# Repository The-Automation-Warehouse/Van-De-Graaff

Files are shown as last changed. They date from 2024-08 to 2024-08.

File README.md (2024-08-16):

# Van-De-Graaff Generator

Made as part of Arcade Hack Club

Used github copilot and Codeium when writing README

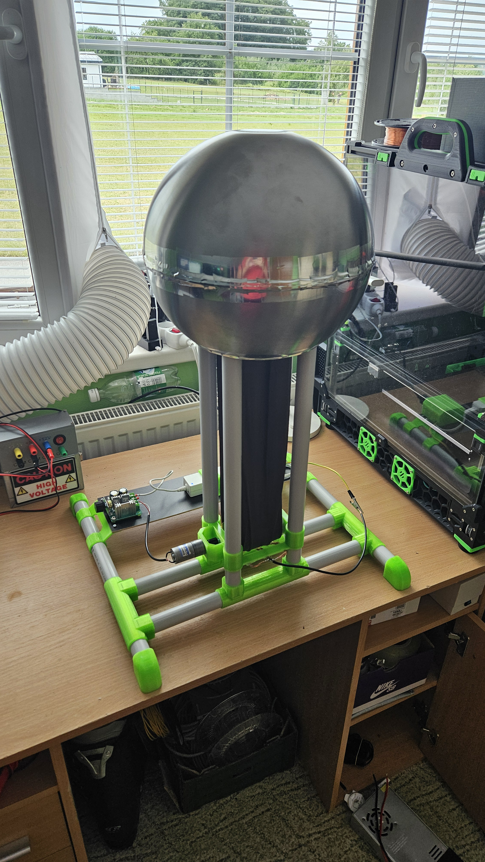
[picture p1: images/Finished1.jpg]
Finished project image

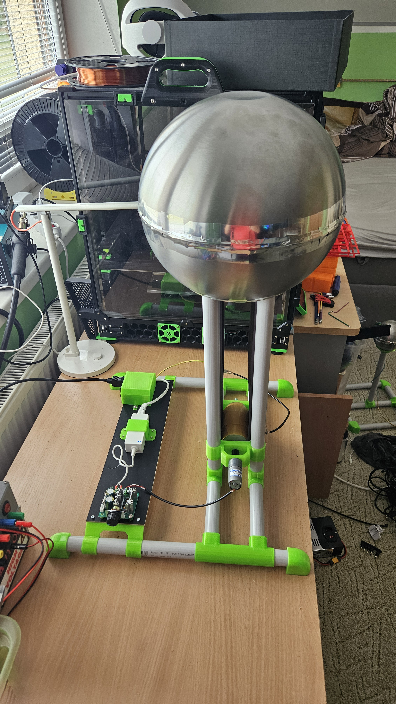
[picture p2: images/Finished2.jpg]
Finished project image


This project is my take on the Van-De-Graaff Generator. 
It is a device that produces high voltage static electricity using the triboelectric effect.
I tried to make it as cheap and simple as possible, using mainly components that can be found in any hardware store.

https://github.com/user-attachments/assets/875eb0bf-50af-4306-b3f1-5c72dd3f4fa9

## How it works
The device works by spinning a belt made of nylon (pantyhose from my moms drawer) around a stationary PVC pipe.
This rubbing action creates a positive charge on the PVC pipe, this charge is then transferred to a metal sphere on top of the device via a closeby brush.
The belt gets negativeley charged and deposits the charge on the bottom of the device, which is connected to the ground thru a second brush.

## Parts
For the generator itself:

- at least 4m of 25mm diameter PVC pipe
- 0.1m of 50mm diameter PVC pipe
- 0.15m of 15mm diameter PVC pipe
- 1.5kg of PETG filament
- some TPU filament for the bottom roller (you can use PETG, and glue some rubber to it)
- a pair of nylone pantyhoses
- for the top sphere: you can get pre-made one, but those can be expensive. I made mine from two almost round 28cm diameter IKEA BLANDA BLANK bowls taped together with aluminum tape
- some wire for the brushes
- a small motor (I used a 6V DC motor running at 12V to get enough torque)
- a 12V power supply
- 100x380x4mm wood board
- DC motor controller
- C13 socket
- 150cm of M8 threaded rod
- 2x M8 Lock nuts
- 2x20 Hardened steel pin
- Some M3 and M5 screws
- some M3 threaded inserts
- 2 608 bearings

If you want to build the optional ground ball:
- at least 4m of 25mm diameter PVC pipe
- for the sphere: same as the top sphere, but you can use a smaller size bowl (I used 12cm diameter)
- some PETG filament
- some wire

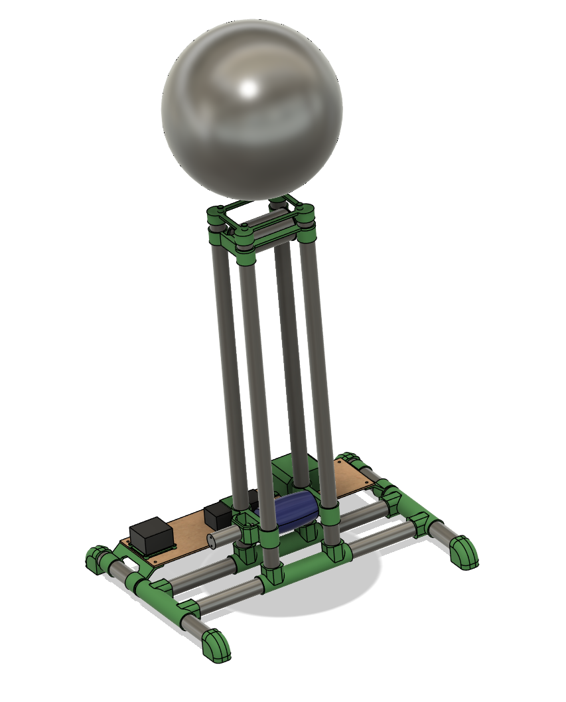
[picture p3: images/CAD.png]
CAD


## Assembly

### Base

1. Cut the 25mm PVC pipe to 4 pieces of 40cm each.
2. Joint them together with 4 printed T-joints.
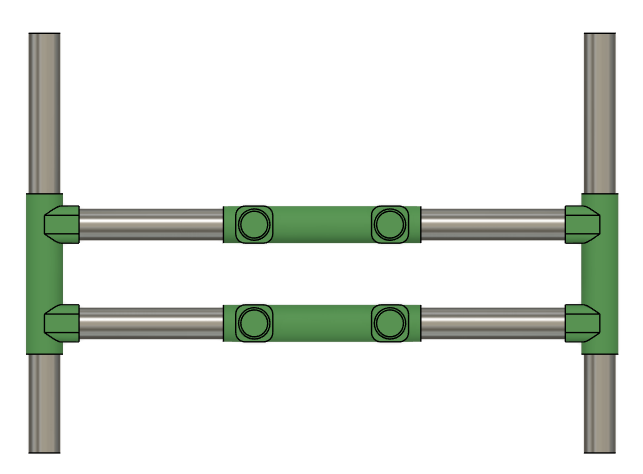
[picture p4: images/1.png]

3. Cut the 50mm PVC pipe to 4 more pieces of 60cm each.
4. Insert them into the base T-joints.
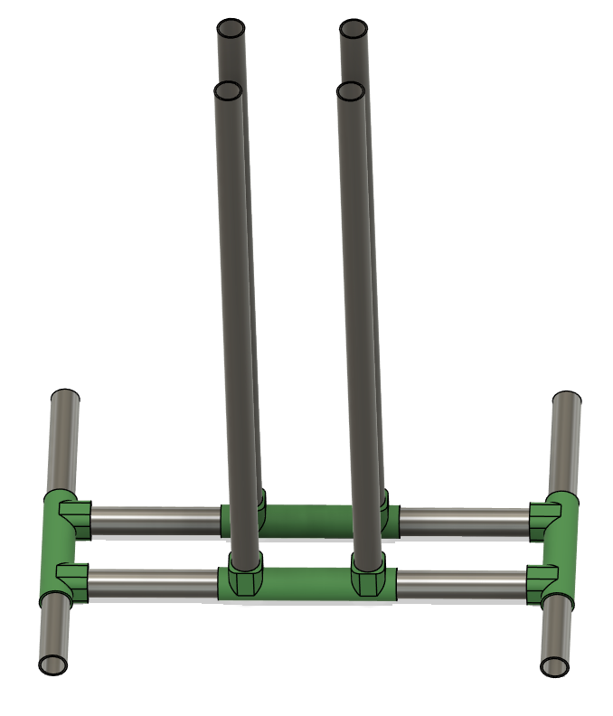
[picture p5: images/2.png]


### Motor mount
1. Insert the 608 bearings into the holders
2. Drill a cross hole at the end of the threaded rod
3. Insert the rod and motor into the printed coupler and fasten the rod with a pin
4. Attach the motor with 2 M3x8 screws. to its mount
5. Slide the lock nuts into the printed roller and use some force to screw the rod into the roller
5. Slide on the bearing holders
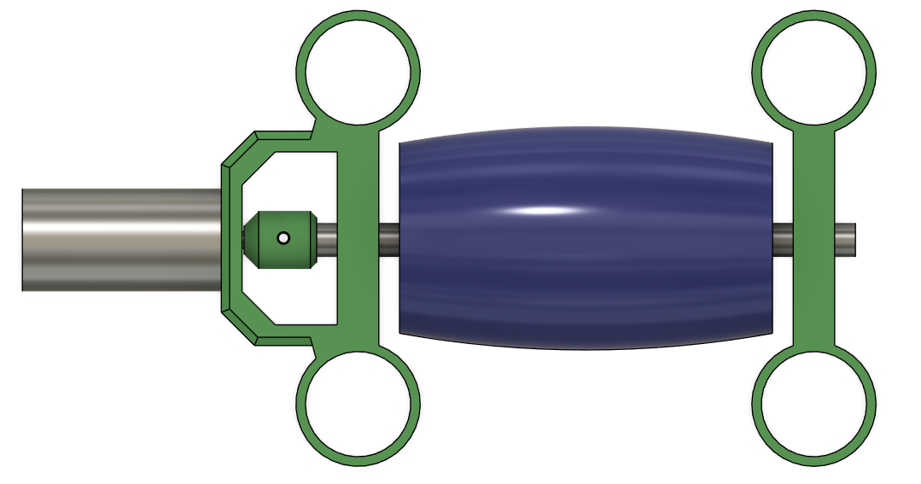
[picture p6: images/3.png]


### Belt
1. Cut the pantyhose to 2 pieces of 55cm each
2. Sew them together to make the belt
3. Cut off any excess material at the seams
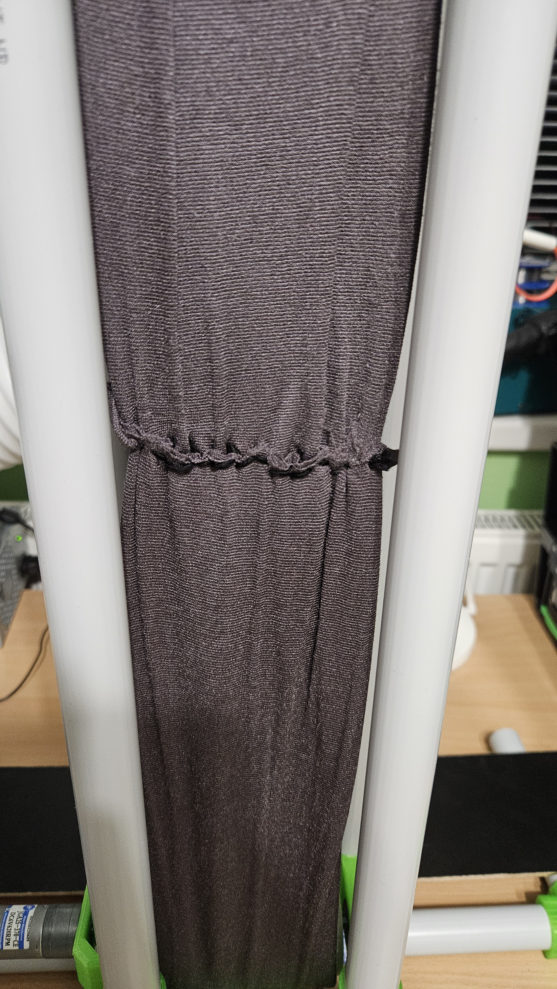
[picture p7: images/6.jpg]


### Brushes
1. Strip some stranded wire
2. Hotglue 3-5 bundles to the brush holder
3. Solder the ends to a longer wire and leave some slack
4. Repeat for the other brush (you can make more brushes if you want)
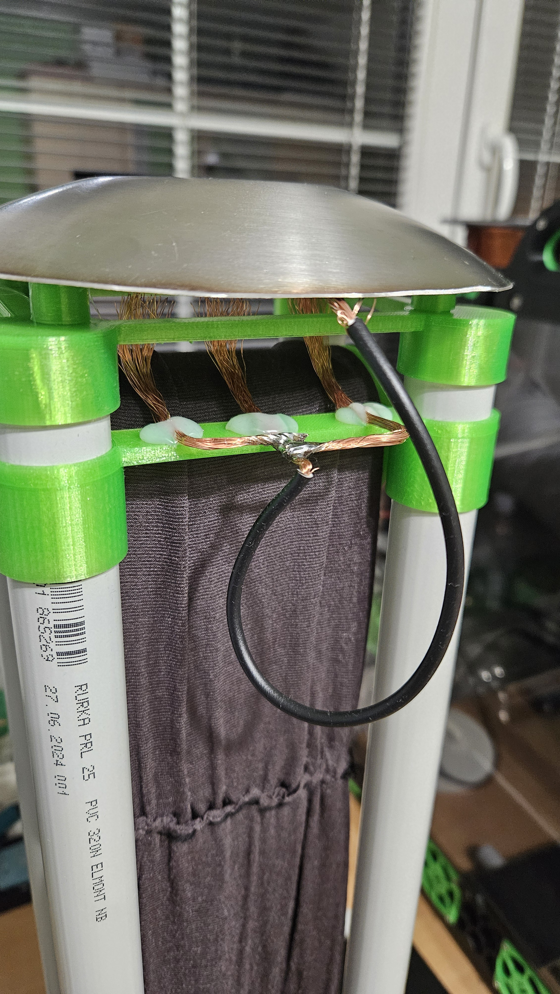
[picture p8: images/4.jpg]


### Top roller
1. Cut the 50mm PVC pipe to 10cm (you might need to shorten it later to make it fit)
2. Inser the two printer holders into it
3. Cut the 15mm PVC pipe to 12cm (you might need to shorten it later to make it fit)
4. Insert it into printed holder
5. Insert the entire assembly into the two printed holders
6. Make sure nothing can rotate - these parts are all press-fit and must remain stationary
7. Use glue if necessary to make it all stay together
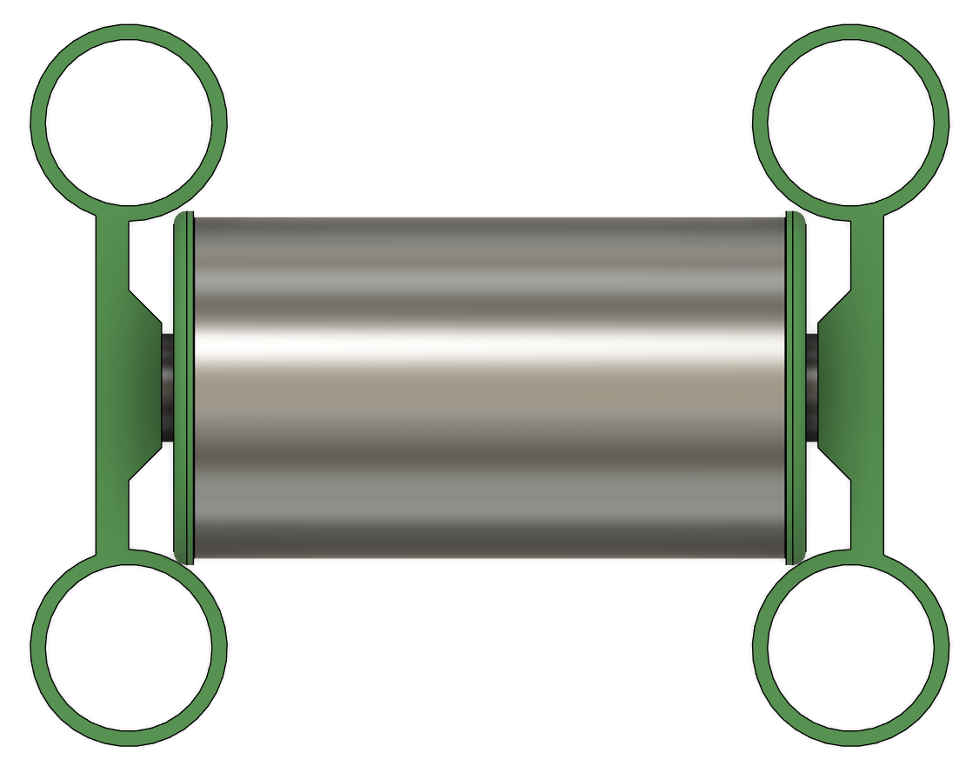
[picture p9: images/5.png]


### Top sphere
If you went the DIY route, this is the most difficult part.
1. Take one of the bowls use and angle grinder to cut a 17-18cm diameter hole in the bottom and make sure to save the cutout piece
2. Tape the two bowls together with aluminum tape (I suggest using a small piece of tape to not get many wrinkles)
3. Use a piece of wire insulation to cover the sharp edge of the bowl
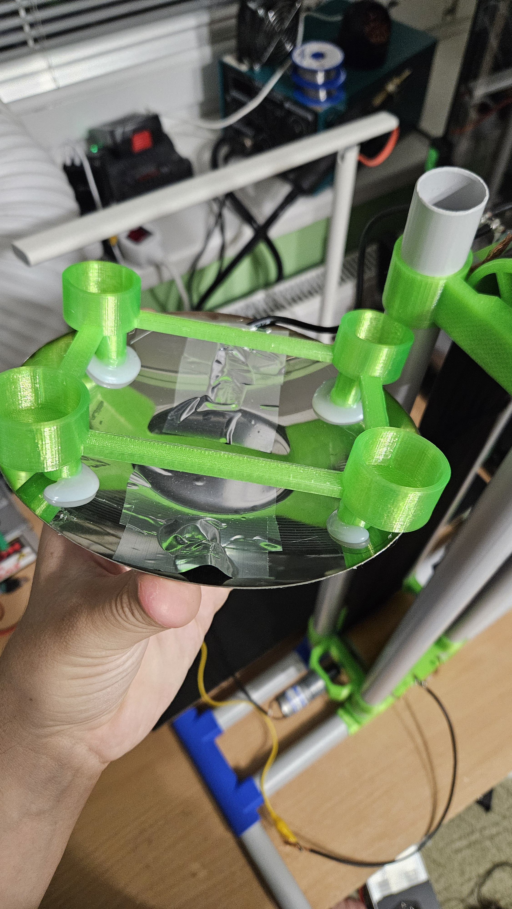
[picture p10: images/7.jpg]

5. (optional) Cover the wire with aluminum tape
6. Glue the cutout piece to the printed holder (you might need add the printed spacers to raise the sphere)
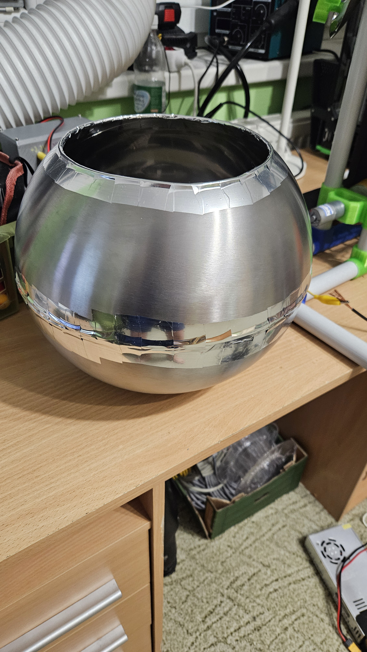
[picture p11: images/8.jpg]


### Base plate and electronics
1. Slide the base plate mounts onto the base
2. Add 4 heat inserts to the base plate mounts
3. Screw the base plate to the mounts


:warning:    :warning:    :electric_plug:    :warning:     :warning: 

Warning: This parts includes mains voltage, if you are not a experienced electrician, skip this part and use a bench power supply instead.

:warning:    :warning:    :electric_plug:    :warning:     :warning: 

4. Attach the motor controller to the base plate with the printed mount
5. Attach power supply and C13 socket to the base plate with the printed mounts (you might need a different mount for you PSU)
6. Connect everything together as schematics show exept for the motor
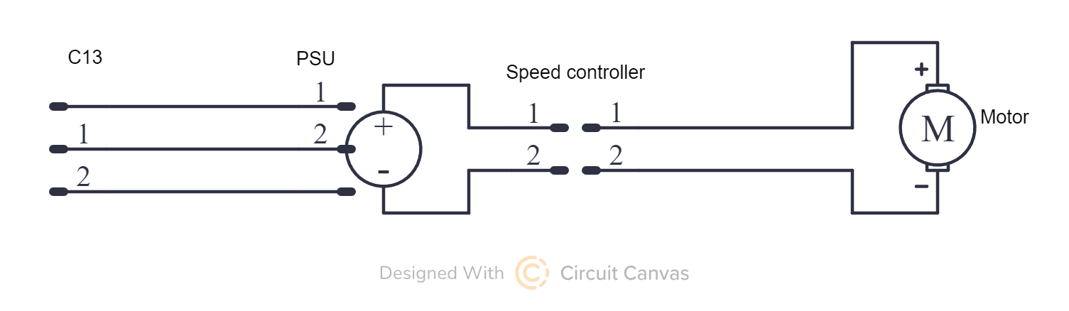
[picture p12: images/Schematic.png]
Schematic


### Final assembly
This part can be a bit finicky with the belt alignment.
1. Slide the belt over the two rollers
2. Slide the components onto the pillars in this order (reference the CAD image)
- bottom brush
- motor mount with roller
- top brush (optional)
- top roller
- top brush
2. Connect the top brush to the top sphere cutout piece with aluminum tape
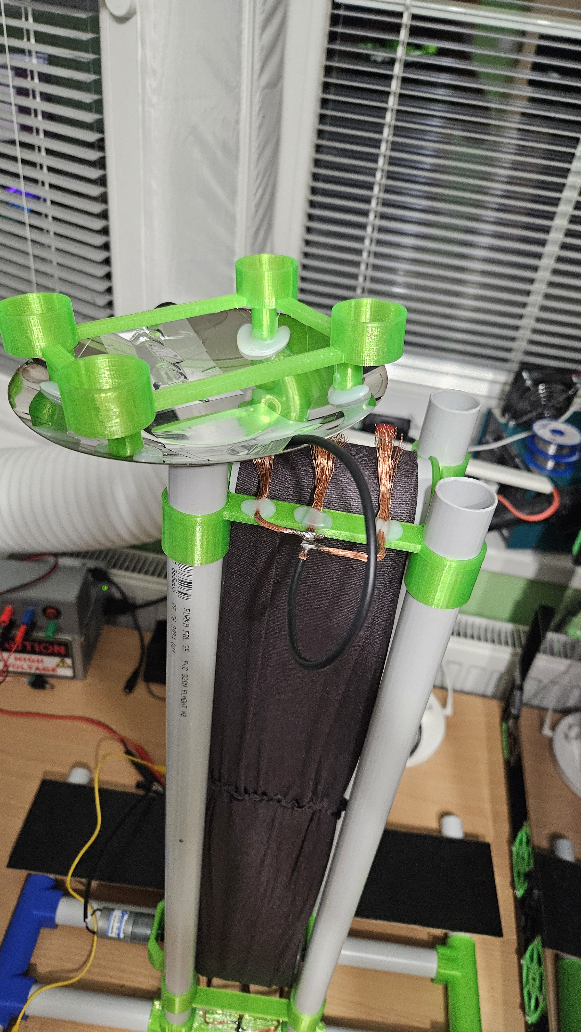
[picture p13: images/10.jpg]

3. Place the top sphere holder on top of everything
4. Place the top sphere on top of the holder
5. Connect the motor to the motor controller
6. You are done!
7. Test it!

If you bring your hand close to the top sphere and feel a shock, it works!

## Ground ball (optional)
1. Cut the 25mm PVC pipe to 5 pieces of 22cm each and 1 piece of 35cm
2. Joint them together with 3 printed T-joints and 4 printed corners while passing a wire from the top to the middle bottom of one pipe (see CAD, I connectd mine thru a 3.5mm audio jack, would not recommend as it does not fit very well and its unnecessary)
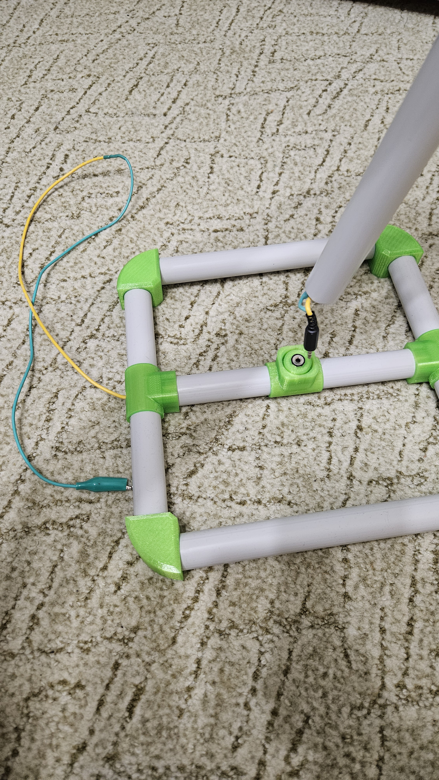
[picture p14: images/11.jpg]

3. Place the sphere holder on top of the pipes
4. Attach the wire to the sphere with aluminum tape
5. Place and glue the sphere on top of the holder
6. (optional) solder a aliigator clip to the other end of the wire
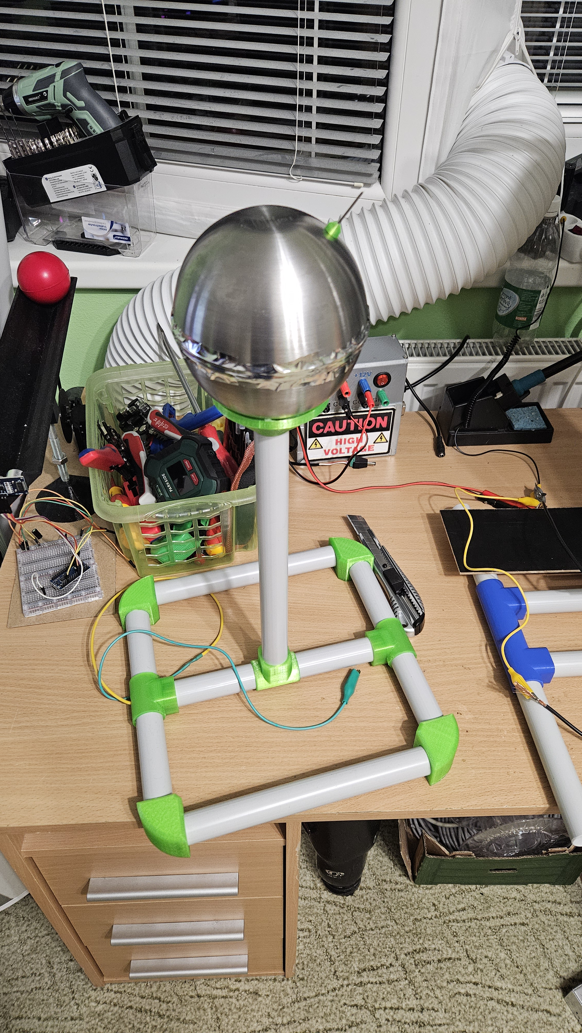
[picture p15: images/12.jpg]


## Fine tuning
1. If the belt is too loose, you can try moving to rollers apart or shorten the belt.
2. Make sure to adjust the brushes so they are close to the belt (they dont have to touch it), but keep them oriented in the direction of the belt so that they dont catch on the seams.
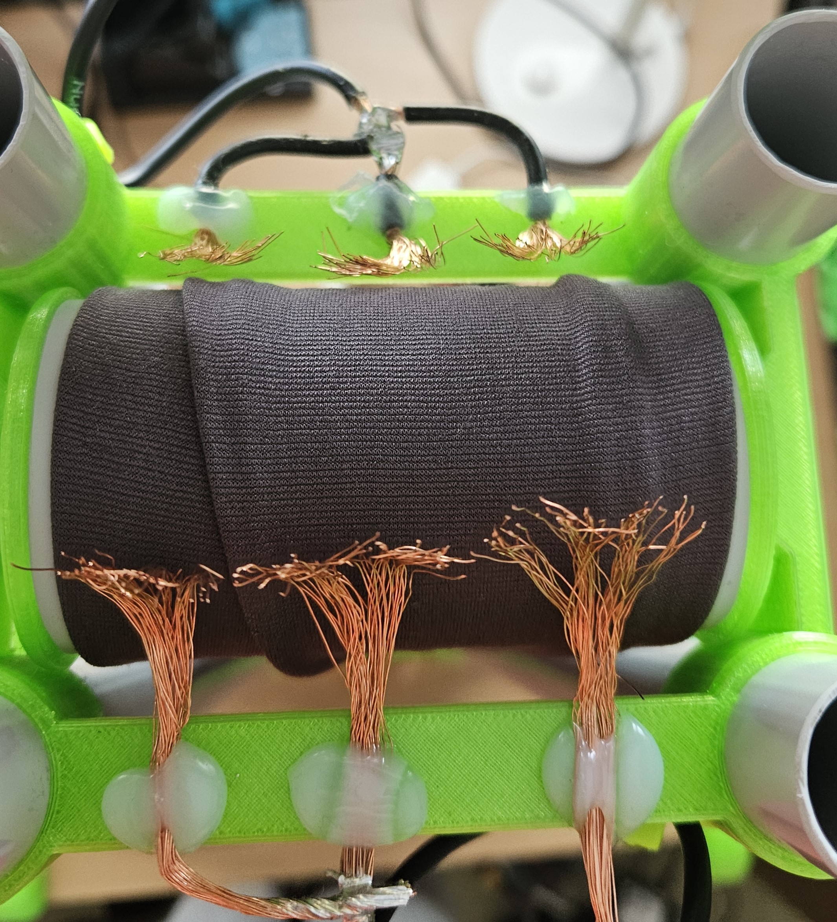
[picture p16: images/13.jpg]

3. Set the motor speed so that it has enough torque to spin the belt (more speed = more charge, but more wear on the belt)
4. Connect the bottom brush to ground or to the optional ground ball.
5. Remove any shap edges on the sphere to prevent corona discharge.

I was able to achive 5-6cm sparks with this setup (around 150-200kV), but I have not spent much time tweaking it, so you might be able to get more out of it.

## Enjoy your new Van-De-Graaff Generator!

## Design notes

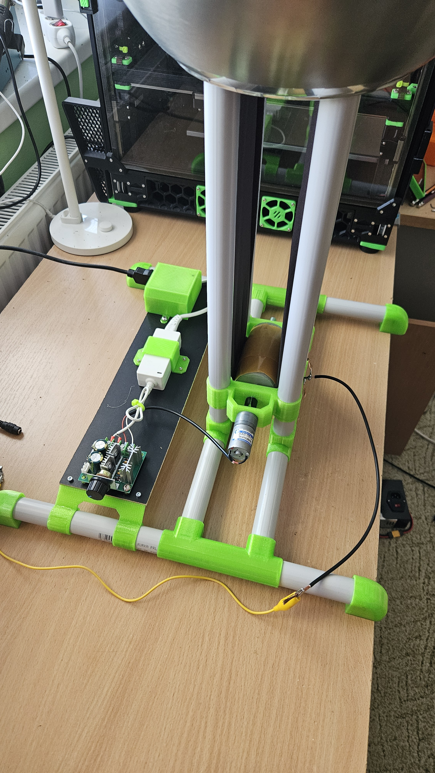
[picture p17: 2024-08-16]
making of/Electronics mounted.jpg

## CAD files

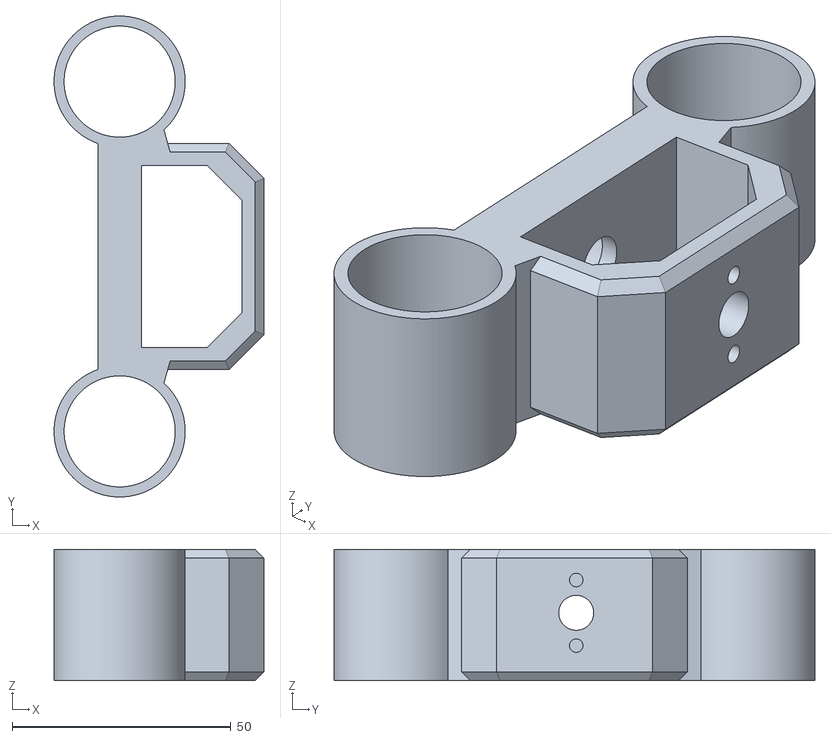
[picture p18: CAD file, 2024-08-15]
CAD/Generator/Bottom Roller Mount - 2.stl
48.0 x 110.0 x 30.0

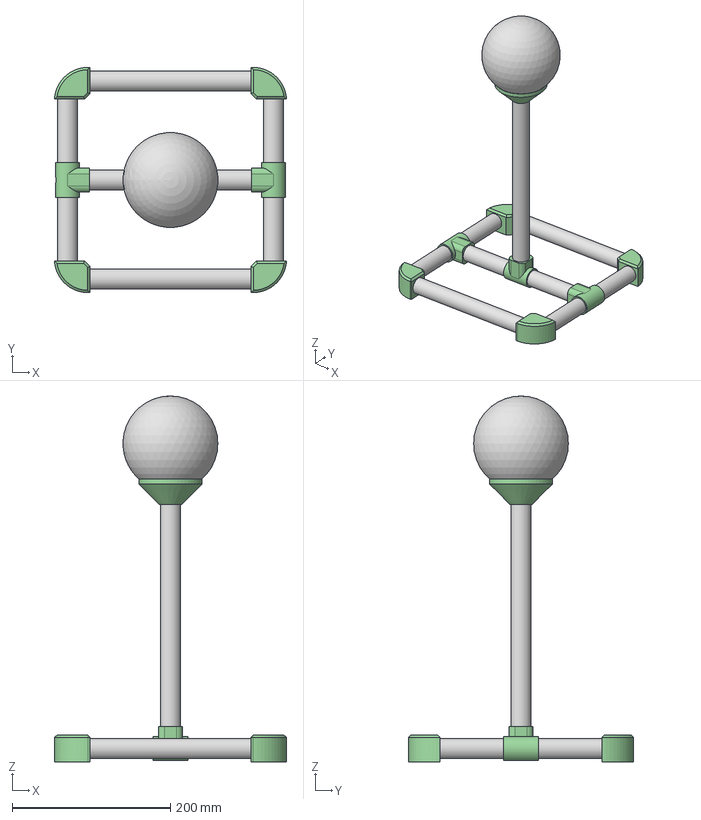
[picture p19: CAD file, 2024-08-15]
CAD/Ground ball/Ground Ball.step
293.1 x 284.4 x 462.0 mm

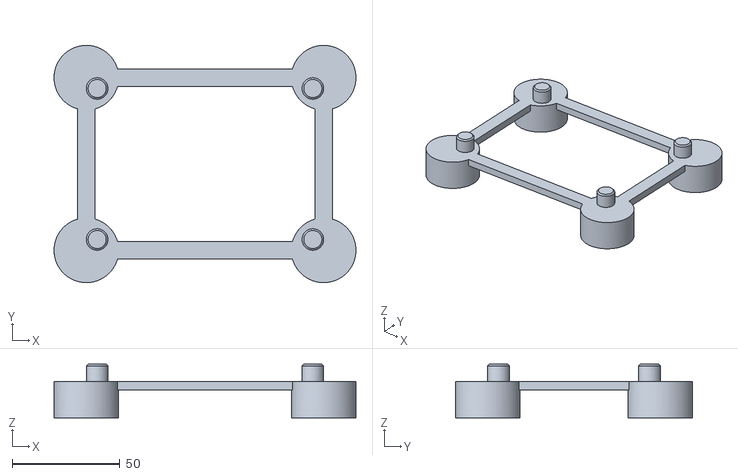
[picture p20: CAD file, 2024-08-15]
CAD/Generator/Top Load Holder.stl
140.0 x 110.0 x 25.0

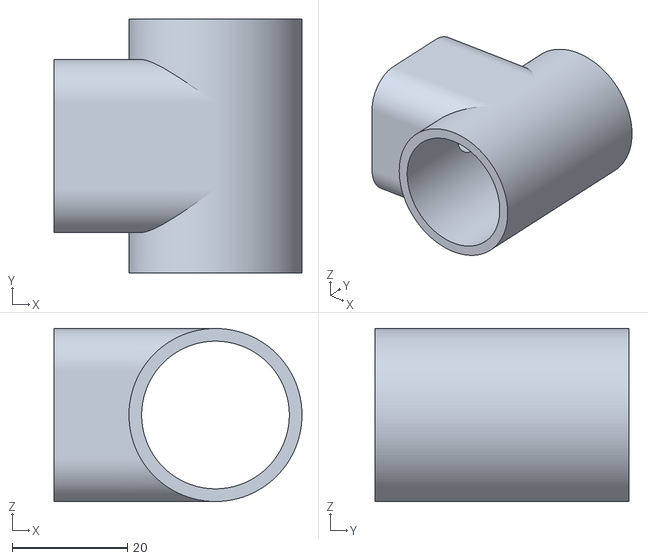
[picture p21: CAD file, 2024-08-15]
CAD/Ground ball/T-Joint 3x.stl
43.0 x 44.0 x 30.0

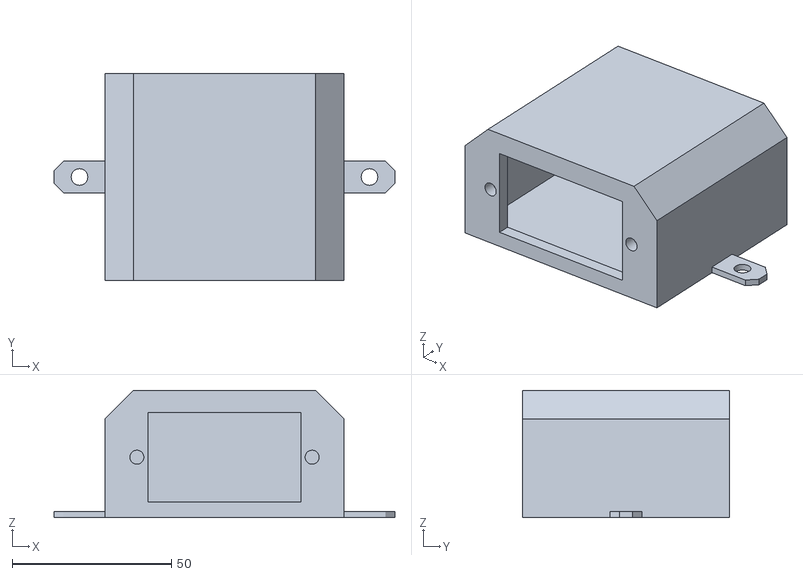
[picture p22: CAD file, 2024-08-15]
CAD/Generator/C13 Mount.stl
107.0 x 65.0 x 40.0

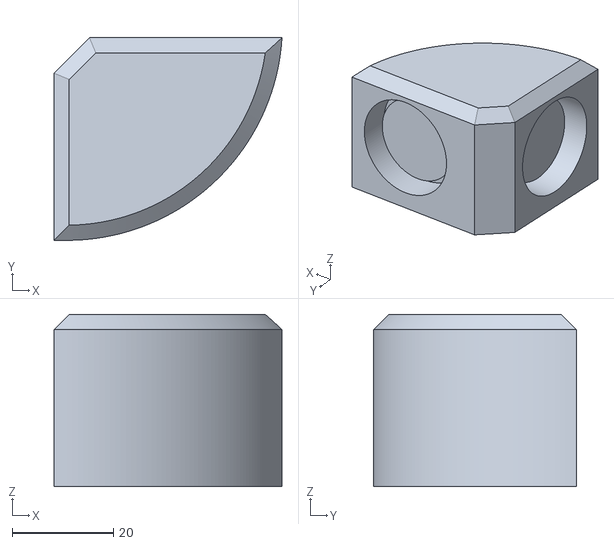
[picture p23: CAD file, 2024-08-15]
CAD/Ground ball/Corner Joint 4x.stl
45.0 x 40.0 x 34.0

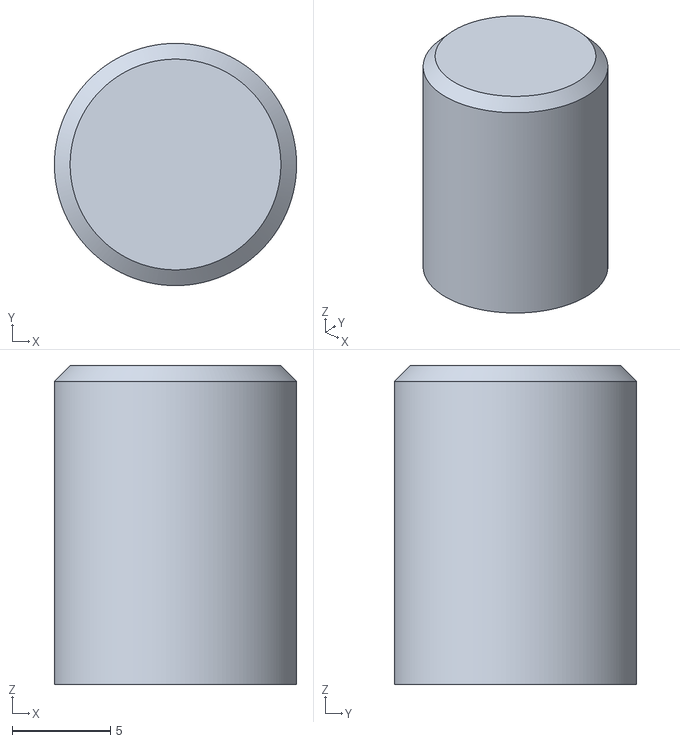
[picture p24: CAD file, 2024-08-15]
CAD/Generator/Spacer 4x.stl
12.3 x 12.3 x 16.2

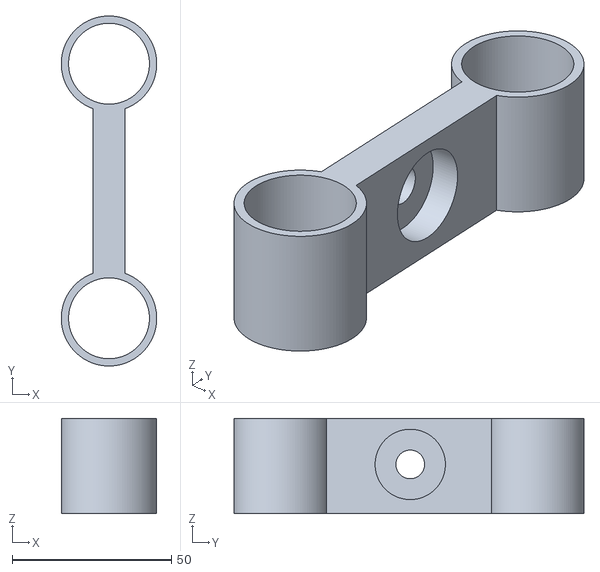
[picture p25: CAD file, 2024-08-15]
CAD/Generator/Bottom Roller Mount - 1.stl
30.0 x 110.0 x 30.0

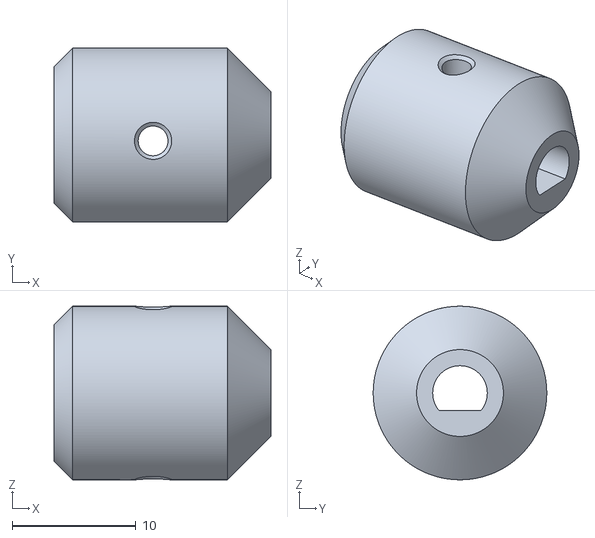
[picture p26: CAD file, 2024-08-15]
CAD/Generator/Motor Coupler.stl
17.5 x 14.0 x 14.0

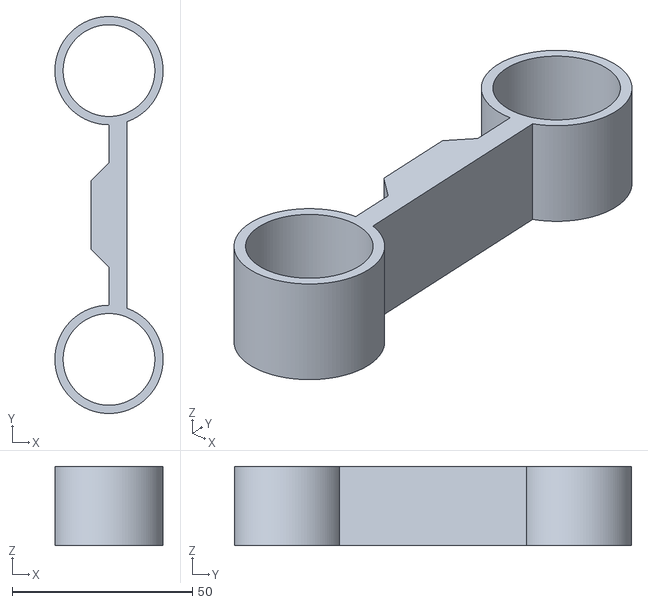
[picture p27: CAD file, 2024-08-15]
CAD/Generator/Top Roller Mount - 2.stl
30.0 x 110.0 x 22.0

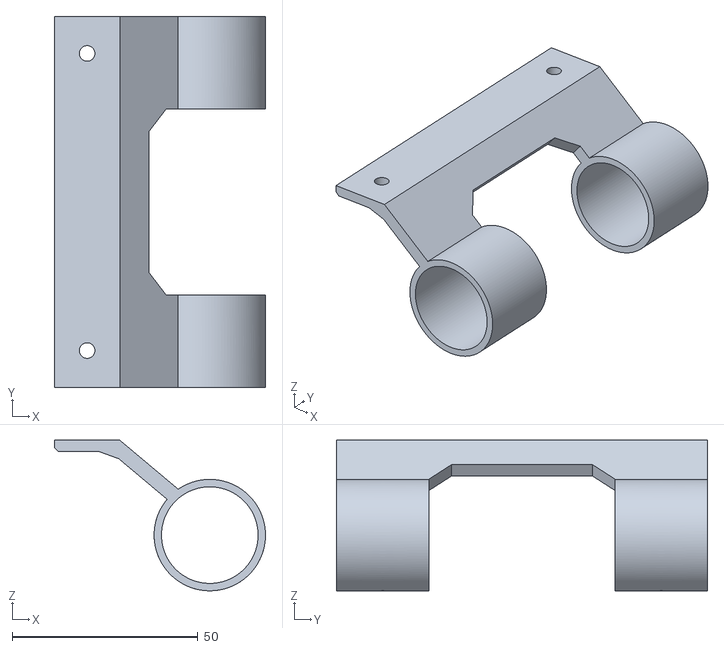
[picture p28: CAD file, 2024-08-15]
CAD/Generator/Base Board Mount 1.stl
56.8 x 100.0 x 40.6

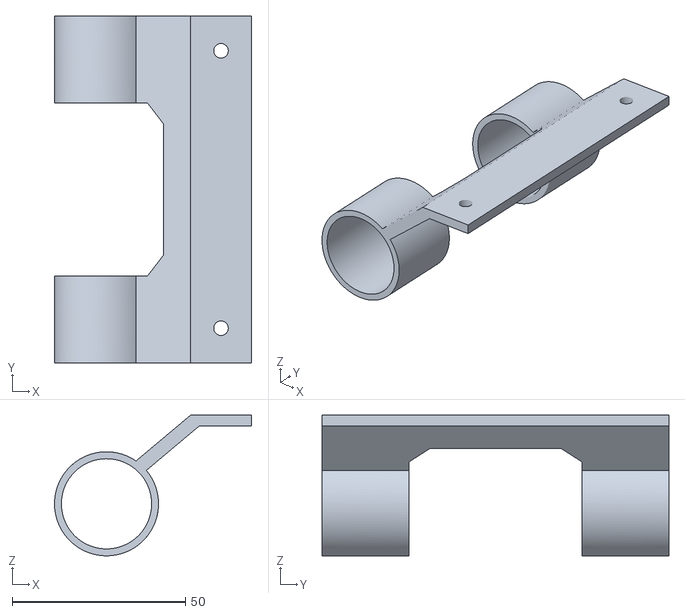
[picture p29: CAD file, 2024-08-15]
CAD/Generator/Base Board Mount 2.stl
56.8 x 100.0 x 40.6

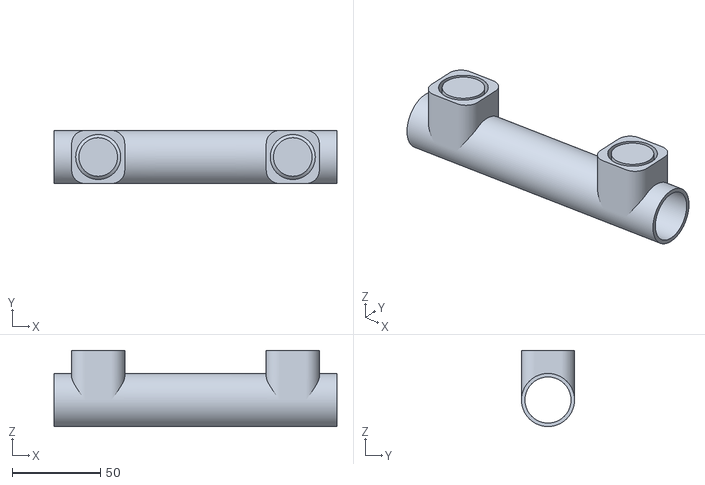
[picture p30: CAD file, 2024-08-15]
CAD/Generator/T-Joint Long - 2.stl
160.0 x 30.0 x 43.0

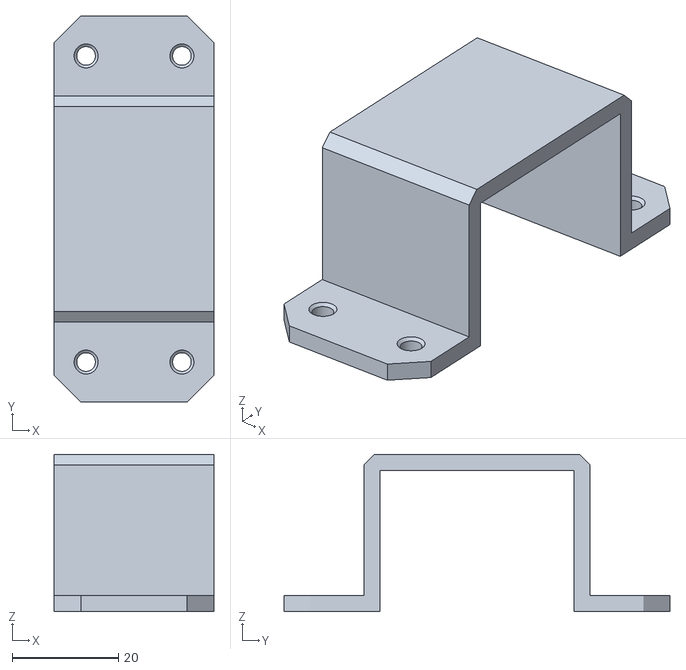
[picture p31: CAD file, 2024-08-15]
CAD/Generator/PSU Holder.stl
30.0 x 72.5 x 29.5

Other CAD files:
CAD/Generator/Top Roller - 2.stl
CAD/Generator/Bottom Roller.stl
CAD/Generator/Foot 4x.stl
CAD/Generator/Top Roller Mount - 1.stl
CAD/Generator/Generator.3mf
CAD/Generator/Generator.step
CAD/Generator/Speed Controller Mount.stl
CAD/Generator/T-Joint Long -1.stl
CAD/Generator/T-Joint Short - 1.stl
CAD/Generator/T-Joint Short - 2.stl
CAD/Generator/Top Brush.stl
CAD/Generator/Top Roller - 1.stl
CAD/Ground ball/Ground Ball.3mf

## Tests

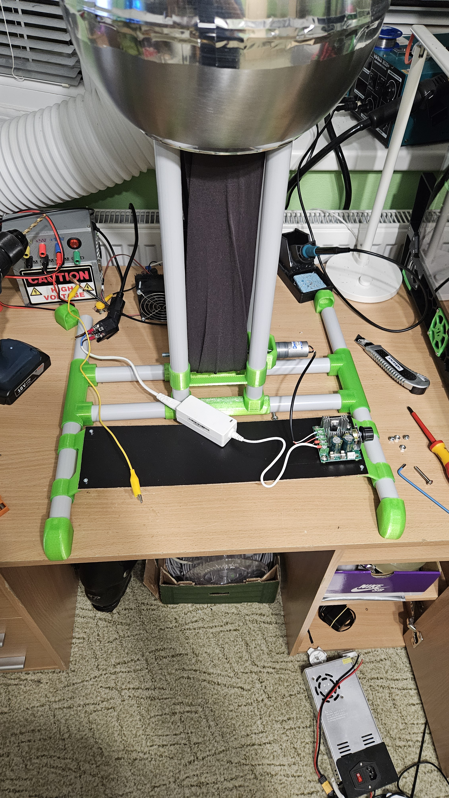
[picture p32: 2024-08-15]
making of/Speed Controller test.jpg

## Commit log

2024-08-15 Added STEP files
    [Generator.step, Ground Ball.step]
2024-08-15 Added STL files
    [Base Board Mount 1.stl, Base Board Mount 2.stl, Bottom Roller Mount - 1.stl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]
2024-08-16 Added Electronics mounted image
